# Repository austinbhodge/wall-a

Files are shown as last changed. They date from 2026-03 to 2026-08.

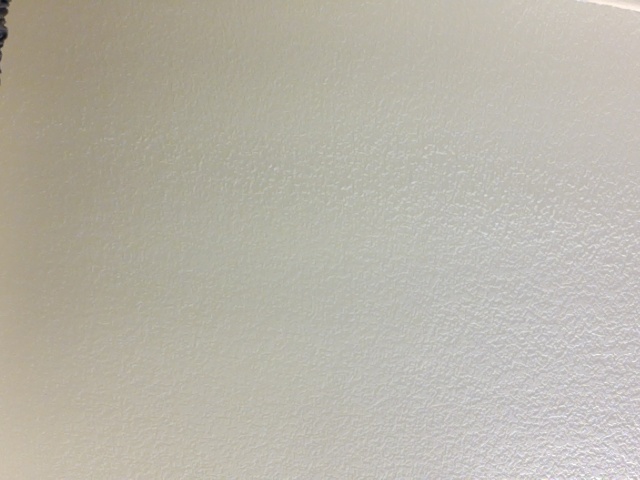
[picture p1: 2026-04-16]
hardware/firsts/2026-04-16-first-camera-frame.jpg

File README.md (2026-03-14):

# Wall-A

A companion robot inspired by Wall-E, built on a 3D-printed tank chassis. The north-star goal: an autonomous trash-collecting machine with personality.

## Architecture

Three compute layers working together:

| Layer | Hardware | Role |
|---|---|---|
| **Firmware** | Arduino Uno + Motor Shield | Motor control, sensor reads, serial JSON |
| **Pi App** | Raspberry Pi 5 | Camera, audio, serial bridge, odometry |
| **GPU Server** | Desktop (GTX 3060) | YOLO vision, Whisper STT, Ollama LLM, Piper TTS |

See [CLAUDE.md](CLAUDE.md) for full architecture, data flow, hardware BOM, and roadmap.

## Project Structure

```
firmware/arduino/   — PlatformIO C++ (Arduino Uno)
pi/                 — Python package (Raspberry Pi 5)
server/             — Python package (GPU desktop)
shared/schemas/     — Protocol definitions (serial, WebSocket)
hardware/           — STLs, CAD, print guides, BOM
scripts/            — Deploy and flash helpers
```

## Quick Start

```bash
# Flash Arduino firmware
./scripts/flash-arduino.sh

# Deploy to Pi
./scripts/deploy-pi.sh

# Run GPU server locally
cd server && pip install -e . && walla-server
```

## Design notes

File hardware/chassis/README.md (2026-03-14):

# Chassis — 3D Printed Tank

Based on [Thingiverse thing:2753227](https://www.thingiverse.com/thing:2753227) — a small tracked robot for prototyping using 22mm skateboard bearings.

## Print Settings

| Setting | Value |
|---|---|
| Material | PLA or PETG |
| Layer Height | 0.2mm |
| Infill | 20-30% |
| Supports | Yes (for sprocket/idler bearing seats) |
| Printer | Bambu Lab A1 Mini (120mm+ bed) |

## Assembly

- 8x 22mm skateboard bearings (8mm bore, 7mm thick)
- 24x M3 screws (10mm)
- 28x M3 nuts
- 8x M3 standoffs (30mm)
- 1x Tamiya 70097 Twin-Motor Gearbox Kit (set to **203:1 gear ratio**)

## Attribution

Original design by the Thingiverse creator for classroom prototyping. Source CAD files are not available. If you modify any STLs, document your changes here.

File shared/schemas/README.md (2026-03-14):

# Shared Schemas

Protocol definitions and message schemas shared between Wall-A's components.

## Serial Protocol (`serial_protocol.json`)

JSON messages sent between the Raspberry Pi and Arduino over USB serial at 115200 baud. Each message is a single JSON object terminated by a newline.

**Direction: Pi → Arduino**
- `motor` — Set left/right motor speeds (-255 to 255)

**Direction: Arduino → Pi**
- `sensors` — Periodic sensor readings (motors, battery, bump sensors)
- `status` — Status/lifecycle messages

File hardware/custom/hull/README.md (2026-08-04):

# Wall-A Electronics Shelves (v0.5)

> **Before printing anything: run `python sim/simulate.py`** — the
> [digital-twin simulation](sim/README.md) checks every solid (parts,
> boards, batteries, fasteners, driver access, keep-outs) and must report
> 0 FAIL. `sim/wall_a.FCStd` is the full assembly for FreeCAD.

Two printed shelves that use the MR6 chassis's **own shelf system**
(Thingiverse thing:2753227) — no base plate, no walls, open-air access.
Parametric Python ([hull.py](hull.py), build123d); re-run `python hull.py`
to regenerate STL + STEP. Both print flat, no supports.

| Piece | Position | Carries |
|---|---|---|
| `uno_shelf` | middle-shelf rails, chassis z 18.5..21.5 (slide in from the front) | Arduino Uno + OSEPP shield on 4mm bosses, ports forward. USB-B pokes 4mm past the front edge; M3/M4 motor terminals hang over the open rear edge, right above where the Tamiya leads rise. |
| `batt_bracket` ×2 | feet on the stock **30mm standoffs** (holes at the standoff line, plain M3×10), legs outboard of the shield, flange segments at the ends with deck pilots — the gaps between segments keep the foot screws driver-accessible | One STL printed **twice** (symmetric — same part both sides, printed lying flat for strength). Together the two brackets form the `_∏_` bridge over the Uno. |
| `batt_deck` | 80 × 139 flat plate on the bracket flanges, chassis z 77.5..80.5; bolts come **up from below** into nuts seated in hex pockets on the deck top | **Both batteries, stacked**: the 71.7 × 135 × 15.8 pi/arduino pack on the bed (side rails, 12 tall), the 65.4 × 117.4 × 7.2 motor pack on top of it — zip-ties/velcro through the grid hold the pair. Four edge towers (at ±38.25) with **cross-nut slots** near their tops carry the pi_shelf. Leaves the **28.5mm wire tunnel** over the shield. |
| `pi_shelf` | 80-wide flat plate on the deck towers, chassis z 104.5..107.5, M3×12 into the tower cross-nuts | Pi 5 on 5mm bosses, USB-A/Ethernet flush with the front edge, USB-C/HDMI at the open +W edge. Board at chassis z 112.5, top 131.2. |

Both shelves use the stock 4-hole pattern — chassis (x −94.5/−27.5,
y 27.5/56.9) — nuts below the `uno_shelf` (as the stock middle shelf),
standoffs through it, screws or nuts on top of the `pi_shelf` (as the
stock top shelf). A 10mm-pitch Ø3.2 prototyping grid covers both plates.

## The height chain (why this works)

Caliper-measured on the real hardware (2026-07-22): Uno PCB bottom → top
of the stacked OSEPP shield = **23.5 mm**.

```
21.5  uno_shelf top
+4.0  bosses
+23.5 Uno + shield stack        -> 49.0 stack top
51.5  standoff tops = bracket feet
77.5  deck underside            -> 28.5 mm WIRE TUNNEL (user-measured need)
80.5  battery bed
      ..96.3  pi/arduino pack (15.8, measured)
      ..103.5 motor pack on top (7.2, measured)
104.5 towers top = pi_shelf underside  -> 1.0 mm over the packs
112.5 Pi board, top of Pi 131.2
```

fit_check asserts this chain on every build, plus: single-solid STLs,
hole-to-boss alignment against the reference models (Pi 0.012mm,
Uno 0.37mm), and standoff/hardware clearance to both boards (7.5mm Uno,
5.4mm Pi).

## ⚠ Verify before printing

At the middle-shelf level the shield sits **between the mounts (60.0mm
gap)**. The OSEPP terminal blocks overhang the 53.4 board — measure the
shield's total width across the blocks: it must be **< 59.5mm** to slide
in. If it's wider, say the word and the bosses get taller (the stack can
ride above the mount tops at the cost of the 2.5mm margin — or the Pi
shelf gains taller standoffs).

## Assembly

1. Click 4 M3 nuts under the middle-rail positions (stock cages).
2. Bench-mount the Uno + shield on `uno_shelf`; slide it into the middle
   rails from the front; drop the 30mm standoffs through the 4 holes into
   the nuts.
3. Wire the motors (leads rise behind the shelf's rear edge into the
   rear-facing M3/M4 blocks) and power. Full open access.
4. Bench-mount the Pi on `pi_shelf`; set it on the standoffs; screw down.
5. Pi→Uno USB A-to-B: short loop down the open front.

## Hardware

Everything is **through-bolted with nuts** (no self-tapping anywhere) using
the user's M2–M5 button-head + nut assortment. Printed in **PETG**.

- 4× M3 nuts + 4× 30mm M3 standoffs — the stock shelf kit (middle rails)
- 4× **M3×8** — bracket feet down into the standoffs (open sky above every
  foot screw — the flanges sit beyond the foot ends)
- 4× **M3×12** — up from under the flanges into **M3 nuts seated in hex
  pockets** on the deck top (flush under the battery)
- 4× **M3×12 + nuts** — pi_shelf down into the tower **cross-nut slots**
  (slide a nut into each slot near the tower top; the screw threads into
  it — towers are too tall for through-bolts)
- 4× **M3×12 + nuts** — Uno through its bosses, nuts under the shelf
- 4× **M2×12 + nuts + washers** — Pi through its bosses (M2 passes the
  Pi's Ø2.7 board holes; washer under each nut)

## Print settings (A1 Mini, PLA/PETG)

**PETG**, 0.2mm layers, 4 walls, 15% infill (PETG: dry filament, slower
outer walls). Every part prints flat with **no supports** — including
`batt_bracket` (print it lying on its side face, twice) and `batt_deck`
(towers and rails point up).

## Roadmap

- [ ] Body shell + Wall-E head (Camera Module 3 eye) that drops over the
      shelf stack — the previous head/eye geometry lives in git history
- [ ] Battery placement (bottom-shelf bay or rear over the gearbox)
- [ ] Front bumper if the forward plugs prove exposed

Reference models live in `hardware/reference/` (gitignored);
[analyze_mr6.py](analyze_mr6.py) / [render_mount.py](render_mount.py)
document the measured chassis interface (`preview/mount_sections.png`).

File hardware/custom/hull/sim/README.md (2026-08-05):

# Wall-A Simulation Harness

The digital twin: every physical object modeled as a solid, checked for
interference, clearance, keep-outs, and **staged driver access** before
anything gets printed.

## Run the simulation

```bash
python sim/simulate.py
```

- Builds all ~80 solids in the chassis frame: printed parts (exact STEP),
  MR6 chassis meshes, measured board envelopes, both measured battery
  packs, standoffs, every screw/nut/washer, wire-tunnel keep-out.
- Checks: exact OCCT pairwise interference · chassis-mesh proximity ·
  keep-out intrusion · per-fastener driver volumes staged by assembly
  order (25mm stubby = FAIL, 80mm straight = WARN).
- Output: `report.txt` (exit 1 on FAIL), `manifest.json` + `proxies/`.

Known accepted WARNs: the two front deck bolts want a stubby driver or
ball-end key for a perfectly straight approach.

## View the assembly (FreeCAD)

```bash
& "C:\Program Files\FreeCAD 1.1\bin\python.exe" sim/build_fcstd.py
```

Then open `sim/wall_a.FCStd` in FreeCAD — the whole robot, grouped
(Chassis / Printed / Electronics / Batteries / Fasteners / Keepouts) and
colored; the wire tunnel is the translucent red box.

## Drive FreeCAD from Claude (MCP)

One-time setup, already installed:
- pip package `freecad-mcp` (the MCP server, wired in `../../../.mcp.json`
  at the repo root — Claude Code picks it up automatically in this repo)
- the `FreeCADMCP` addon in `%APPDATA%\FreeCAD\v1-1\Mod` (note: FreeCAD
  1.x reads the **versioned** user dir, not the old `FreeCAD\Mod`)

To use it: open FreeCAD → select the **MCP Addon** workbench →
**Start RPC Server** (localhost:9875) → start a Claude Code session in
this repo and approve the `freecad` MCP server. Claude can then create/
edit objects, run scripts, and screenshot the viewport live.

## What the sim caught on its first runs (why this exists)

- Pi mounting nuts protruding 1.1mm into the motor pack (fixed: flush
  underside hex pockets)
- deck-bolt heads and driver paths colliding with the bracket legs
  (fixed: bolt line moved inboard, flanges widened)
- foot-screw drivers blocked by the bracket web's top chord (fixed:
  full-height access windows)
- tower cross-nut corners clipping the wide battery lane (fixed: slots
  raised above the pack)
- independently confirmed the MR6 rail cage voids line up with the
  standoff nuts/studs

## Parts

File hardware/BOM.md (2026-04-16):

# Bill of Materials

## Chassis & Mechanical

| Part | Qty | Notes | Link |
|---|-----|---|---|
| 3D Printed Tank Chassis | 1 set | [Thingiverse thing:2753227](https://www.thingiverse.com/thing:2753227) | |
| Tamiya 70097 Twin-Motor Gearbox | 1 | Set to 203:1 ratio | |
| M3 Screws (10mm) | 24 | | |
| M3 Nuts | 28 | | |
| M3 Standoffs (30mm) | 8 | | |
| 22mm Skateboard Bearings | 8 | 8mm bore, 7mm thick | |

## Electronics

| Part | Qty | Notes |
|---|-----|---|
| Raspberry Pi 5 | 1 | Headless Ubuntu 24.04 Server |
| Arduino Uno | 1 | Low-level motor/sensor control |
| Motor Shield (Arduino) | 1 | Drives Tamiya twin motors |
| Raspberry Pi Camera Module 3 | 1 | imx708 sensor, 4608×2592, CSI ribbon to CAM/DISP 0 |
| USB Microphone | 1 | Speech input |
| Small Speaker | 1 | TTS output |
| USB Power Bank | 1 | Powers Pi 5 via USB-C |
| Motor Battery Pack | 1 | Separate power for motors |

## GPU Server (Desktop)

| Part | Qty | Notes |
|---|-----|---|
| NVIDIA GTX 3060 (12GB) | 1 | Inference: YOLO, Whisper, LLM, TTS |

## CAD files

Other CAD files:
hardware/custom/hull/step/hull_assembly.step
hardware/custom/hull/step/shell_sleeve.step
hardware/custom/hull/step/uno_shelf.step
hardware/custom/hull/step/shell_roof.step
hardware/custom/hull/step/pi_shelf.step
hardware/custom/hull/step/batt_bracket.step
hardware/custom/hull/step/batt_deck.step
hardware/custom/hull/stl/batt_bracket.stl
hardware/custom/hull/stl/batt_deck.stl
hardware/custom/hull/stl/pi_shelf.stl
hardware/custom/hull/stl/shell_roof.stl
hardware/custom/hull/stl/shell_sleeve.stl
hardware/custom/hull/stl/uno_shelf.stl

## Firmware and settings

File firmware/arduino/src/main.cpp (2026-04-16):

#include <Arduino.h>
#include <ArduinoJson.h>
#include <AFMotor.h>

// Motor Shield v1 (L293D) — motors on M1 and M2
AF_DCMotor motorLeft(1);
AF_DCMotor motorRight(2);

// Serial JSON buffer
JsonDocument doc;

void setMotors(int leftSpeed, int rightSpeed) {
    // leftSpeed/rightSpeed: -255 to 255
    leftSpeed = constrain(leftSpeed, -255, 255);
    rightSpeed = constrain(rightSpeed, -255, 255);

    motorLeft.setSpeed(abs(leftSpeed));
    if (leftSpeed > 0) motorLeft.run(FORWARD);
    else if (leftSpeed < 0) motorLeft.run(BACKWARD);
    else motorLeft.run(RELEASE);

    motorRight.setSpeed(abs(rightSpeed));
    if (rightSpeed > 0) motorRight.run(FORWARD);
    else if (rightSpeed < 0) motorRight.run(BACKWARD);
    else motorRight.run(RELEASE);
}

void sendSensorData() {
    doc.clear();
    doc["type"] = "sensors";
    doc["motors"]["left_speed"] = 0;  // TODO: read encoder
    doc["motors"]["right_speed"] = 0;
    doc["battery_voltage"] = analogRead(A0) * (5.0 / 1023.0) * 2.0; // voltage divider
    doc["bump_sensors"]["front_left"] = false;   // TODO: wire bump sensor
    doc["bump_sensors"]["front_right"] = false;

    serializeJson(doc, Serial);
    Serial.println();
}

void handleCommand() {
    if (!Serial.available()) return;

    String input = Serial.readStringUntil('\n');
    DeserializationError error = deserializeJson(doc, input);
    if (error) return;

    const char* type = doc["type"];
    if (!type) return;

    if (strcmp(type, "motor") == 0) {
        int left = doc["left"] | 0;
        int right = doc["right"] | 0;
        setMotors(left, right);
    }
}

void setup() {
    Serial.begin(115200);

    // Stop all motors
    setMotors(0, 0);

    // Announce ready
    doc.clear();
    doc["type"] = "status";
    doc["message"] = "Wall-A firmware ready (Motor Shield v1, M1+M2)";
    serializeJson(doc, Serial);
    Serial.println();
}

void loop() {
    handleCommand();

    // Send sensor data at ~10Hz
    static unsigned long lastSend = 0;
    if (millis() - lastSend >= 100) {
        sendSensorData();
        lastSend = millis();
    }
}

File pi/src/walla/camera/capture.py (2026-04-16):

"""Camera capture for the Pi Camera Module 3 via libcamera (Picamera2)."""

import logging

from picamera2 import Picamera2

log = logging.getLogger(__name__)


class Camera:
    def __init__(self, device: int = 0, width: int = 320, height: int = 240):
        self.device = device
        self.width = width
        self.height = height
        self._cam: Picamera2 | None = None

    def open(self) -> bool:
        log.info("Opening Pi Camera %d (%dx%d)", self.device, self.width, self.height)
        try:
            self._cam = Picamera2(self.device)
            # Picamera2's "RGB888" format produces byte-order BGR arrays — cv2-compatible.
            config = self._cam.create_video_configuration(
                main={"size": (self.width, self.height), "format": "RGB888"}
            )
            self._cam.configure(config)
            self._cam.start()
            return True
        except Exception as e:
            log.warning("Camera unavailable: %s", e)
            self._cam = None
            return False

    @property
    def connected(self) -> bool:
        return self._cam is not None

    def try_reconnect(self) -> bool:
        """Attempt to (re)open the camera. Returns True only if newly connected."""
        if self.connected:
            return False
        return self.open()

    def read_frame(self):
        """Read a single frame. Returns (success, BGR ndarray)."""
        if not self._cam:
            return False, None
        try:
            return True, self._cam.capture_array("main")
        except Exception:
            log.exception("capture_array failed — dropping camera")
            self._drop()
            return False, None

    def _drop(self):
        try:
            if self._cam:
                self._cam.stop()
                self._cam.close()
        except Exception:
            pass
        self._cam = None

    def close(self):
        self._drop()

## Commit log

2026-04-02 Implement manual and autonomous driving modes for Wall-A
    - Rewrite Arduino firmware for Adafruit Motor Shield v1 (L293D) with
    AFMotor library, motors on M3 (left) and M4 (right)
    - Add DualSense PS5 controller support via evdev (headless-compatible)
    with arcade-style tank drive on left stick
    - Add HSV floor-segmentation autonomous navigator with obstacle
    avoidance state machine (patrol, turn, reverse) and bump sensor override
    - Rewrite Pi main.py as threaded orchestrator: sensor + camera on
    background threads, 20Hz control loop with mode switching
    - Fix camera capture.py missing self parameter, lower default
    resolution to 320x240, use explicit V4L2 backend
    - Add thread-safe shared R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
    [bridge.py, capture.py, main.cpp]
2026-04-16 Switch camera to Pi Camera Module 3 (CSI/libcamera)
    Replaces the planned Logitech C270 USB webcam with the imx708-based
    Pi Camera Module 3 over the CSI ribbon. The Camera class now uses
    Picamera2 instead of cv2.VideoCapture; the open/read_frame/close
    interface is unchanged so threads.py and main.py keep working.
    Frames stay BGR (via Picamera2's "RGB888" byte ordering) so the
    existing cv2-based navigator/detector pipeline is unaffected.
    [capture.py]
2026-04-16 Controller hot-reconnect, axis rotation fix, M1/M2 motor wiring
    - Gamepad: add try_reconnect() and rotate stick axes 90° (X↔Y) to match
    the controller orientation.
    - main.py: poll for controller every 2s when disconnected; stop forcing
    AUTO mode at startup when no controller is present.
    - Firmware: motors moved from M3/M4 to M1/M2 on the Motor Shield v1;
    ready-message updated to match.
    - Add walla.service systemd unit so the app starts on boot.
    [main.cpp]
2026-04-16 Make Wall-A robust to missing Arduino and camera
    Every device is now optional at startup. SerialBridge.connect() and
    Camera.open() return a bool and log a warning instead of raising when
    the hardware is missing. Both gain a try_reconnect() and a connected
    property mirroring the existing Gamepad pattern.
    The single 2s reconnect tick in main.py now retries all three
    (controller, Arduino, camera) so any device can be hot-plugged.
    The sensor thread sleeps when the bridge is disconnected to avoid
    spinning at 100% CPU. I/O failures during read/write drop the bridge
    or camera so the next reconnect attempt picks them back up.
    Status log now reflects live bridge.connected and camera.connected
    inste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
    [bridge.py, capture.py]
2026-04-16 Add Wall-A's first camera frame
    Captured from the Pi Camera Module 3 (imx708) immediately after the
    Picamera2 swap was wired in — the very first image the robot ever
    saw of the world. Pointed at a wall.
2026-04-18 Add web dashboard for remote monitoring and control
    Stdlib-only HTTP server on :8080 serves an MJPEG camera stream,
    live diagnostics, log tail, and a WEB drive mode gated by a 500ms
    watchdog in the main tick loop.
2026-08-04 Add electronics shelf stack (v0.5), digital-twin simulation, and FreeCAD MCP
    Parametric build123d shelf system for the MR6 chassis: uno_shelf in the
    middle rails, battery bridge (2x bracket + 80mm deck carrying both
    measured packs over a 28.5mm wire tunnel), pi_shelf on cross-nut towers.
    All through-bolted with the M2-M5 kit, PETG, support-free prints.
    sim/: full digital twin (~80 solids incl. every fastener and staged
    driver-access volumes) with exact OCCT interference checks — caught and
    fixed Pi nuts vs motor pack, deck bolts vs bracket legs, blocked foot
    drivers, and tower nuts vs battery before printing. build_fcstd.py
    generates the FreeCAD assembly; .mcp.json wires the freecad-mcp s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
    [batt_bracket.step, batt_bracket.stl, batt_deck.step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]
2026-08-04 Add body shell + Wall-E head (v0.6), simulation-verified
    Two support-free pieces: shell_sleeve (registration ribs on the shelf
    edges, interior posts above the wide pack, port/vent windows, open rear
    service bay, M3 side screws into new pi_shelf edge holes) and shell_roof
    (two-eye head, standard Camera Module 3 behind the left eye, ribbon slot,
    cross-nut bolts into the sleeve posts).
    Digital twin now covers the full robot (106 solids, 36 driver checks,
    plug keep-outs through every window, camera sightline): 0 FAIL. The sim
    caught the sleeve posts running through the 135mm battery, tower-nut
    corners against the wall, and seat-screw heads vs the ribs before print.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
    [batt_bracket.step, batt_deck.step, hull_assembly.step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]
2026-08-05 Document current hardware build state in CLAUDE.md for session handoff
    Adds the READ FIRST section: v0.5+v0.6 architecture, sim-gate rule,
    measured constants, fastening/print conventions, FreeCAD paths (incl.
    the versioned v1-1 Mod dir), and MR6 chassis interface facts.
